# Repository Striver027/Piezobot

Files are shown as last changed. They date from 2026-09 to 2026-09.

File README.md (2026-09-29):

# Piezobot

**A desktop-scale, low-cost stick–slip piezoelectric robot for validating
swarm-intelligence algorithms that require fine relative positioning.**

This repository contains the editable hardware design files and firmware that
accompany the HardwareX article on Piezobot. It is intended to be sufficient for
another group to reproduce the robot and reproduce the measurements reported in
the article.

---

## Overview

Piezobot is a small mobile robot whose motion is produced by a **stick–slip
(friction–inertia) mechanism**: two piezoelectric stacks drive the robot across a
flat ferromagnetic surface, while N52 permanent magnets simultaneously provide the
preload force and the friction surface. Driving the stacks with a sawtooth waveform
generates a small net displacement on every cycle, which accumulates into
centimetre-scale travel. Turning is obtained by switching off the drive signal of one
of the two channels.

The robot is built from **stacked PCBs**, so the mechanical structure requires almost
no fasteners and the boards can be substituted to suit different experiments. Its
small size (3.7 cm body diameter) allows a high density of individuals to be placed
within a single camera field of view, which is what makes it useful as a
swarm-robotics test platform.

## Key specifications

| Parameter | Value |
|---|---|
| Body diameter | 3.7 cm |
| Actuation | 2 × piezoelectric stacks, stick–slip (friction–inertia) |
| Preload / friction surface | N52 permanent magnets |
| Drive voltage | 30 V (single Li-ion cell + on-board boost converter) |
| Drive waveform | Sawtooth, 2 kHz, generated by timer-triggered DMA (open loop) |
| Measured travelling speed | ≈ 1.6 mm/s (16 mm in 10 s) |
| Net displacement per drive cycle | ≈ 0.8 µm |
| Steering | Differential — switching off one drive channel turns the robot |
| Position holding | Retained when the drive signal is removed |
| Communication | 433 MHz wireless module |
| Working surface | Flat, ferromagnetic (tests performed on 430 stainless steel) |

> Piezobot is an **open-loop, single-prototype** platform at this stage: displacement
> is estimated from the number of drive cycles, with no position feedback. Positioning
> error is intended to be compensated by the vision system of the swarm-validation
> platform.

## Repository structure

```
Piezobot/
├── README.md                 This file
├── LICENSE                   CC BY-SA 4.0 (full legal text)
├── Hardware/                 Editable PCB source projects, PDFs and Gerber files
│   └── README.md             File-by-file inventory of the hardware folder
├── CAD/                      Mechanical CAD: Fusion 360 sources and neutral STEP files
│   └── README.md             Description of the CAD files
├── Docs/                     Documentation and the editable bill of materials
│   ├── README.md             Index of the documentation
│   └── BOM_<board>.xlsx      Editable bill of materials, one file per board
└── firmware/                 STM32 firmware — to be added before the v1.0 release
```

## Hardware

Four boards are stacked, from bottom to top: **PZT → power → controller → function**. They
share a common power and signal interface. Above the stack, at the very top of the robot,
sits the **LCD board**: the 0.99-inch display is taped onto it, the display ribbon cable is
soldered to it, and it converts the display signals into an FPC interface that connects to
the controller board. Neither the DAP board nor the BAT board is part of the stack: the DAPLink-end adapter in the
DAP board panel is used only as an aid for flashing the firmware, and the BAT board is the
battery adapter that powers the robot.

| Board | Function |
|---|---|
| **PZT board** (bottom of the stack) | Carries and wires the piezoelectric stacks |
| **Power board** | Boost converter (3.7 V → 30 V) and power operational amplifier that generates the drive waveform |
| **Controller board** | STM32G431 main controller; two DAC channels generate the sawtooth waveforms; the FPC from the LCD board connects here |
| **Function board** (top of the stack) | Six-axis IMU and 433 MHz wireless module |
| **LCD board** (above the stack, topmost part of the robot) | Display base board: the 0.99-inch display is taped onto it and its ribbon cable is soldered to it; converts the display signals into an FPC interface |
| **DAP board** (outside the stack) | Panelized adapter (PowerLink 2.54 mm ↔ 0.8 mm BTB): one larger link-end adapter board plus two smaller boards (programming, two batteries); the link-end adapter is used to flash the firmware |
| **BAT board** (outside the stack) | Battery adapter with the same panel structure and layout as the DAP board, but with thickened lead connections, so the two are not interchangeable; used to retrofit the battery that powers the robot |

The PCB sources are **Altium Designer** files (`.PrjPcb`, `.SchDoc`, `.PcbDoc`);
PDF schematics and fabrication-ready Gerber/drill archives are provided alongside them
so that the boards can be reviewed and manufactured without Altium. See
[`Hardware/README.md`](Hardware/README.md) for the complete file inventory.

The mechanical design is provided in [`CAD/`](CAD) in two formats: the editable
Autodesk Fusion 360 sources (`Piezobot_Assembly.f3z`, `CNC/aluminium_base.f3d`) and the
same geometry as neutral STEP files (`Piezobot_Assembly.step`, `CNC/aluminium_base.step`).
The assembly contains all parts of the robot, including the CNC-machined aluminium base
and the 3D-printed shell and LCD retaining ring; the parts to be printed are also
provided as STL. See [`CAD/README.md`](CAD/README.md) for the file inventory.

## Firmware

The firmware runs on an STM32G4-series microcontroller. It generates two 12-bit
sawtooth waveforms through the internal DACs, which the power board amplifies to 30 V
to drive the piezoelectric stacks. The waveform is produced by a timer triggering DMA
transfers, and the travelling speed is controlled by changing the driving frequency
(within the tested range, speed is approximately proportional to frequency).

**Firmware source code: `firmware/` — _to be added before the v1.0 release._**

## Getting started

1. Assemble the robot following the article (see *How to cite* below). Details of the
   assembly, including the magnet orientation, the glue points and the contact
   resistance check between the brass screw and the base, are given in the article's
   build instructions.
2. Charge/connect the single Li-ion cell.
3. Place the robot on a flat ferromagnetic surface (the article reports measurements on
   a 430 stainless steel plate).
4. Power the robot: the controller starts generating the 2 kHz sawtooth waveform and
   the robot begins stepping.
5. To change speed, change the driving frequency. To turn, disable the drive signal on
   one of the two channels.
6. Remove the drive signal to stop; the magnets hold the robot in place.

⚠️ **Safety:** the board generates up to 30 V and the magnets are strong N52 magnets —
take care with the boost converter output and avoid pinching fingers between the
magnets and the steel plate. Instant adhesive is used during assembly.

## Bill of materials

Components other than the PCBs. The electronics are itemised board by board in the
editable files in [`Docs/`](Docs) (`BOM_<board>.xlsx`, one per board, in the same column
format as the article's Bill of materials summary).

| Component | Type | Specification | Qty |
|---|---|---|---|
| NdFeB magnet (N52) | Drive | — | 4 |
| piezoelectric stack | Drive | AL1.65×1.65×5D-4F | 2 |
| shell | Structure | 3D printed | 1 |
| LCD retaining ring | Structure | 3D printed | 1 |
| aluminium base | Structure | CNC machined (aluminium) | 1 |
| brass cap screw | Structure | M2.5 × 4 | 2 |
| brass ball plunger | Friction | M4 | 3 |
| FPC | Wiring | — | 1 |
| instant adhesive (401) | Consumable | — | — |
| magnetic pole indicator card | Tool | — | — |

## Documentation

Additional documentation is collected in the [`Docs/`](Docs) folder:

- [`Docs/README.md`](Docs/README.md) — index of the assembly figures, wiring diagram and
  operating notes;
- [`Docs/`](Docs) — editable bills of materials, one file per board (`BOM_<board>.xlsx`),
  in the column format used by the article.

## Licence

All design files in this repository are released under the
**[Creative Commons Attribution-ShareAlike 4.0 International (CC BY-SA 4.0)](LICENSE)**
licence: you are free to use, modify and redistribute them, provided that you give
appropriate credit and license any derivative work under the same terms.

## How to cite

If you use Piezobot in your work, please cite **both** the article and this repository.

**Article**

> *(citation to be completed once the HardwareX article is published)*

**This repository**

```bibtex
@software{piezobot_v1,
  author  = {Xing, Zhizhou},
  title   = {Piezobot: design files and firmware for a stick--slip piezoelectric
             robot for swarm-intelligence algorithm validation},
  year    = {2026},
  version = {v1.0},
  doi     = {10.5281/zenodo.XXXXXXX},
  url     = {https://github.com/Striver027/Piezobot}
}
```

*(The Zenodo DOI will be inserted here once the v1.0 release has been archived.)*

## Contact

Xing Zhizhou — Hebei University of Science and Technology, Shijiazhuang, China
Corresponding author, HardwareX article: `2024102026@stu.hebust.edu.cn`

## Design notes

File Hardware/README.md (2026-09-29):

# Hardware — Piezobot hardware design files

Editable PCB design files for the Piezobot robot

All files in this folder are released under the
**Creative Commons Attribution-ShareAlike 4.0 International (CC BY-SA 4.0)** licence.
See the repository root [`LICENSE`](../LICENSE) for the full text.

---

## File inventory

### Stack order (bottom → top)

| # | Board |
|---|---|
| 1 (bottom) | PZT board |
| 2 | Power board |
| 3 | Controller board |
| 4 (top) | Function board |

The **LCD board** sits above the stack and is the topmost part of the whole robot; its FPC
connects to the controller board.
The **DAP board** and the **BAT board** are not part of the stack and are used only for some
auxiliary functions. In the panels of the DAP board and the BAT board, the larger part is the
DAPLink-end adapter. The small board in the DAP board is an adapter for connecting to the
robot end, and the small board in the BAT board is the battery adapter that powers the robot.

### Project files (open these first)

| File | Format | Purpose |
|---|---|---|
| `Piezobot.PrjPcb` | Altium project | **Master project** — open it with Altium Designer to browse all the schematics and PCB layouts below |
| `Piezobot.OutJob` | Altium output job | Fabrication and documentation output settings for the project |

### PZT board (piezoelectric stack carrier and wiring)

Stack position: bottom (1st from the bottom).

| File | Format | Purpose |
|---|---|---|
| `PZT_board.SchDoc` | Altium schematic | Schematic |
| `PZT_board.PcbDoc` | Altium PCB | PCB layout |
| `PZT_board.pdf` | PDF | Schematic (for viewing without Altium) |
| `PZT_board.zip` | Gerber + drill | Ready for PCB fabrication |

### Power board (boost converter + power operational amplifier)

Stack position: 2nd from the bottom.

| File | Format | Purpose |
|---|---|---|
| `power_board.SchDoc` | Altium schematic | Schematic |
| `power_board.PcbDoc` | Altium PCB | PCB layout |
| `power_board.pdf` | PDF | Schematic (for viewing without Altium) |
| `power_board.zip` | Gerber + drill | Ready for PCB fabrication |

### Controller board (STM32G431 main controller)

Stack position: 3rd from the bottom; the FPC of the LCD board connects to this board.

| File | Format | Purpose |
|---|---|---|
| `controller_board.SchDoc` | Altium schematic | Schematic |
| `controller_board.PcbDoc` | Altium PCB | PCB layout |
| `controller_board.pdf` | PDF | Schematic (for viewing without Altium) |
| `controller_board.zip` | Gerber + drill | Ready for PCB fabrication |

### Function board (IMU + 433 MHz wireless module)

Stack position: top (4th from the bottom).

| File | Format | Purpose |
|---|---|---|
| `function_board.SchDoc` | Altium schematic | Schematic |
| `function_board.PcbDoc` | Altium PCB | PCB layout |
| `function_board.pdf` | PDF | Schematic (for viewing without Altium) |
| `function_board.zip` | Gerber + drill | Ready for PCB fabrication |

### LCD board (screen base board, topmost part of the whole robot)

The 0.99-inch LCD screen is taped onto this board, and the screen ribbon cable is soldered to
this board. This board serves as the base board of the screen and adapts the screen signal
cable to an FPC, which is connected to the controller board through the FPC. It sits above the
stack and is the topmost part of the whole robot.

| File | Format | Purpose |
|---|---|---|
| `LCD_board.SchDoc` | Altium schematic | Schematic |
| `LCD_board.PcbDoc` | Altium PCB | PCB layout |
| `LCD_board.pdf` | PDF | Schematic (for viewing without Altium) |
| `LCD_board.zip` | Gerber + drill | Ready for PCB fabrication |

### DAP board (DAPLink adapter, panelized)

A simple adapter board: different types of connectors are adapted through this circuit board.
The layout of this board is **panelized**: it can adapt the 2.54 mm interface of PowerLink to a
0.8 mm BTB interface. The large board is used to first convert 2.54 mm into 1.27 mm pin
headers, and the small board is used to convert the 1.27 mm pin headers into a 0.8 mm BTB
interface.

| File | Format | Purpose |
|---|---|---|
| `DAP_board.SchDoc` | Altium schematic | Schematic |
| `DAP_board.PcbDoc` | Altium PCB | Panelized layout |
| `DAP_board.pdf` | PDF | Schematic (for viewing without Altium) |
| `DAP_board.zip` | Gerber + drill | Gerber and drill files of the panelized version |

### BAT board (battery adapter, panelized)

Battery adapter board. It has exactly the same structure and layout as the DAP board, but the
lead connections inside the board have been thickened and copper-poured, so the **DAP board and
the BAT board are not interchangeable**: only their large boards are the same — the large board
in the BAT panel can still be connected to a DAPLink programmer, while the small board is used
to retrofit a lithium-battery connector to power the robot.

| File | Format | Purpose |
|---|---|---|
| `BAT_board.SchDoc` | Altium schematic | Schematic |
| `BAT_board.PcbDoc` | Altium PCB | Panelized layout |
| `BAT_board.pdf` | PDF | Schematic (for viewing without Altium) |
| `BAT_board.zip` | Gerber + drill | Gerber and drill files of the panelized version |

---

## PCB fabrication parameters

| Board | Layers | Board thickness |
|---|---|---|
| PZT board | 2 | 1.0 mm |
| Power board | 2 | 1.6 mm |
| Controller board | 4 | 1.6 mm |
| Function board | 2 | 1.2 mm |
| LCD board | 2 | 1.2 mm |
| DAP board | 2 | 1.6 mm |
| BAT board | 2 | 1.6 mm |

Except for the controller board, which is a four-layer board (laminate order from top to
bottom: top layer / mid-layer 1 / mid-layer 2 / bottom layer), all the other boards are
two-layer boards.

The copper weight follows the manufacturer's (JLCPCB) default process: **1 oz on the outer
layers and 0.5 oz on the inner layers** (the inner-layer value applies to the four-layer
controller board).

---

## How to open these files

- **To edit the electronics**: use **Altium Designer** (the `.PrjPcb` project opens all the
  schematics and layouts together). You can also view them in a browser with the free
  **Altium 365 Viewer**.
- **To view without Altium**: use the `.pdf` file of each board (schematic).
- **To fabricate**: send the contents of the corresponding `.zip` (Gerber + drill) to any PCB
  manufacturer.

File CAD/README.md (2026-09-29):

# CAD — Piezobot mechanical design files

Mechanical CAD and 3D-printing files for the Piezobot robot.

All files in this folder are released under the
**Creative Commons Attribution-ShareAlike 4.0 International (CC BY-SA 4.0)** licence.
See the repository root [`LICENSE`](../LICENSE) for the full text.

---

## File inventory

```
CAD/
├── Piezobot_Assembly.f3z               Complete robot assembly (Fusion 360 archive)
├── Piezobot_Assembly.step              Complete robot assembly (neutral STEP)
├── CNC/
│   ├── aluminium_base.f3d              CNC-machined aluminium base (Fusion 360 part)
│   └── aluminium_base.step             CNC-machined aluminium base (neutral STEP)
└── STLs(3D Print)/
    ├── shell.stl                       3D-printed shell
    └── LCD_retaining_ring_0.99in.stl   3D-printed retaining ring for the 0.99-inch LCD
```

| File | Format | Description |
|---|---|---|
| `Piezobot_Assembly.f3z` | Fusion 360 archive | Complete robot assembly — every part is in its assembled position; open this file first if you use Autodesk Fusion 360 |
| `Piezobot_Assembly.step` | STEP assembly | The same complete assembly in neutral STEP format, for any other CAD software |
| `CNC/aluminium_base.f3d` | Fusion 360 part | CNC-machined aluminium base |
| `CNC/aluminium_base.step` | STEP part | The same part in neutral STEP format |
| `STLs(3D Print)/shell.stl` | STL part | 3D-printed shell |
| `STLs(3D Print)/LCD_retaining_ring_0.99in.stl` | STL part | Retaining ring for the 0.99-inch LCD |

## How to use these files

- `Piezobot_Assembly.f3z` and `CNC/aluminium_base.f3d` open directly in Autodesk Fusion 360; the `.step` files carry the same geometry in a neutral format that any CAD software can import.
- `Piezobot_Assembly` contains the whole robot; you can locate a part in the assembly to see its assembled state and position.
- The two `.stl` files can be sliced and 3D printed directly.
- The assembly steps of the mechanical parts are described step by step in the accompanying HardwareX article: including the base and the stick–slip mechanism, the fixing and wiring of the PZT board, and the assembly of the screen, retaining ring and shell.

## Fabrication

| File | Process |
|---|---|
| `CNC/aluminium_base.step` | CNC machining (6061 aluminium) |
| `STLs(3D Print)/shell.stl` | 3D printing (PLA material, 0.2 mm nozzle) |
| `STLs(3D Print)/LCD_retaining_ring_0.99in.stl` | 3D printing (same process as above) |

More detailed printing and machining parameters (material, layer height, infill, etc.) are given in the accompanying article.

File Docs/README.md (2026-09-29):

# Documentation — Piezobot

Supporting documentation for building, operating and reproducing the Piezobot robot.

Everything in this folder is released under the
**Creative Commons Attribution-ShareAlike 4.0 International (CC BY-SA 4.0)** licence.
See the repository root [`LICENSE`](../LICENSE) for the full text.

---

## Bill of materials

The electronics are itemised board by board — one editable spreadsheet per board:

| File | Board |
|---|---|
| `BOM_PZT_board.xlsx` | PZT board |
| `BOM_power_board.xlsx` | power board |
| `BOM_controller_board.xlsx` | controller board |
| `BOM_function_board.xlsx` | function board |
| `BOM_LCD_board.xlsx` | LCD board |
| `BOM_DAP_board.xlsx` | DAP board |
| `BOM_BAT_board.xlsx` | BAT board |

Every file uses exactly the same columns as the *Bill of materials summary* in the
article:

```
Designator, Component, Number of units, Cost per unit - CNY,
Total cost - CNY, Source of materials, Material type
```

The first row of each file is the bare-board fabrication cost (JLCPCB, 21.6 CNY per
board). The `Source of materials` cells are hyperlinks to *Taobao* or *LCSC*. The total
of each file is the cost of that board.

The parts other than the PCBs, together with the board-level totals, are listed in the
*Bill of materials summary* of the article.

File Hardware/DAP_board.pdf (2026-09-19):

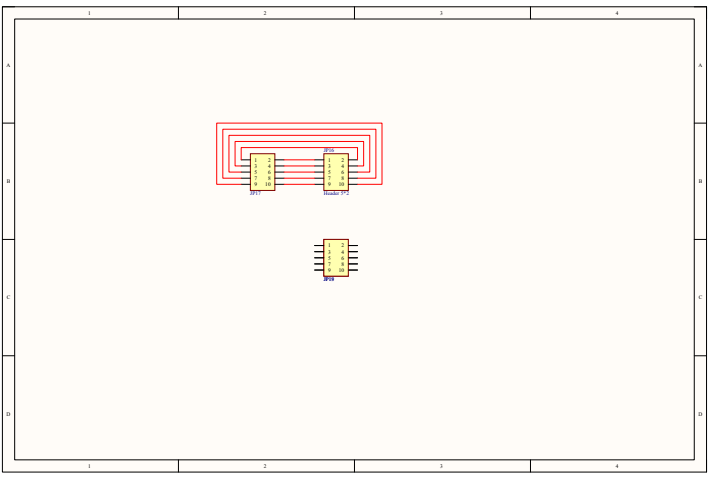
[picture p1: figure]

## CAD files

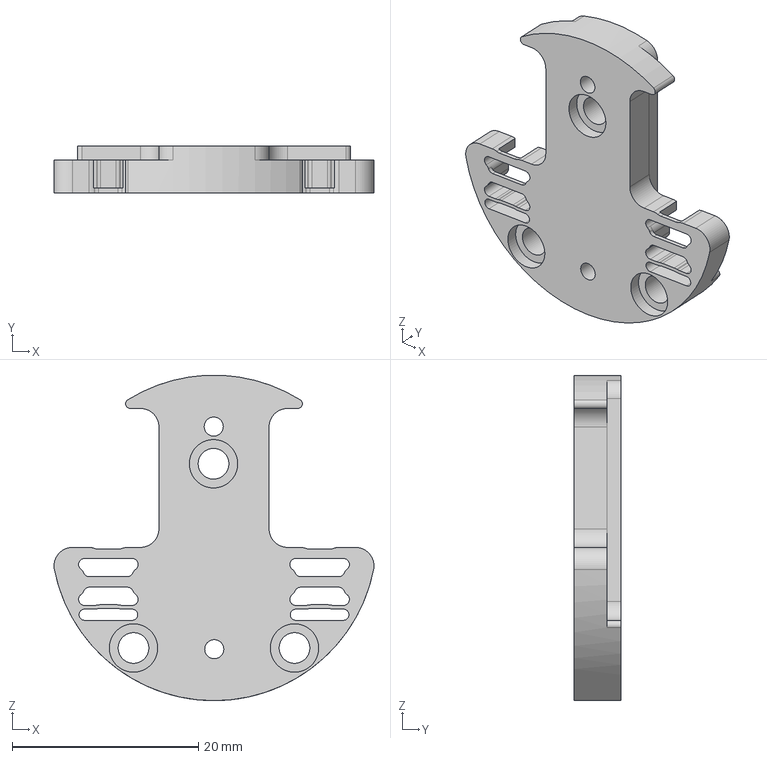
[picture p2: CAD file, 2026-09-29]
CAD/CNC/aluminium_base.step
34.4 x 5.00 x 35.0 mm

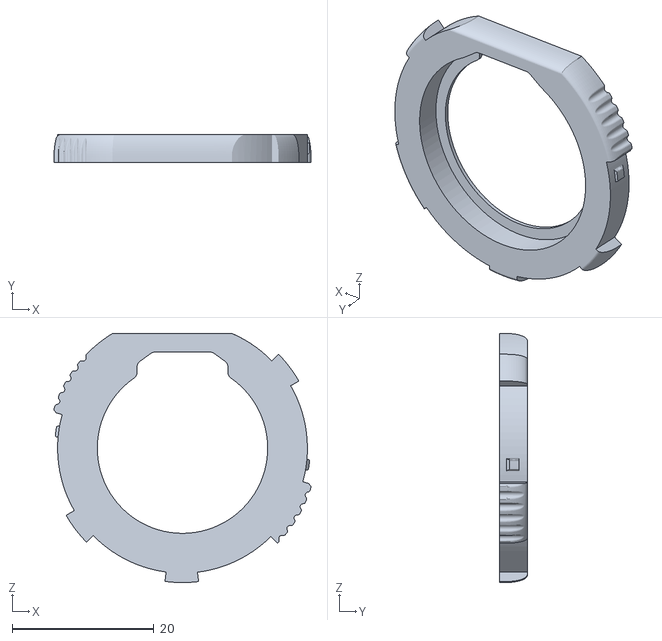
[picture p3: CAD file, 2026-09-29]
CAD/STLs(3D Print)/LCD_retaining_ring_0.99in.stl
36.2 x 3.90 x 35.1

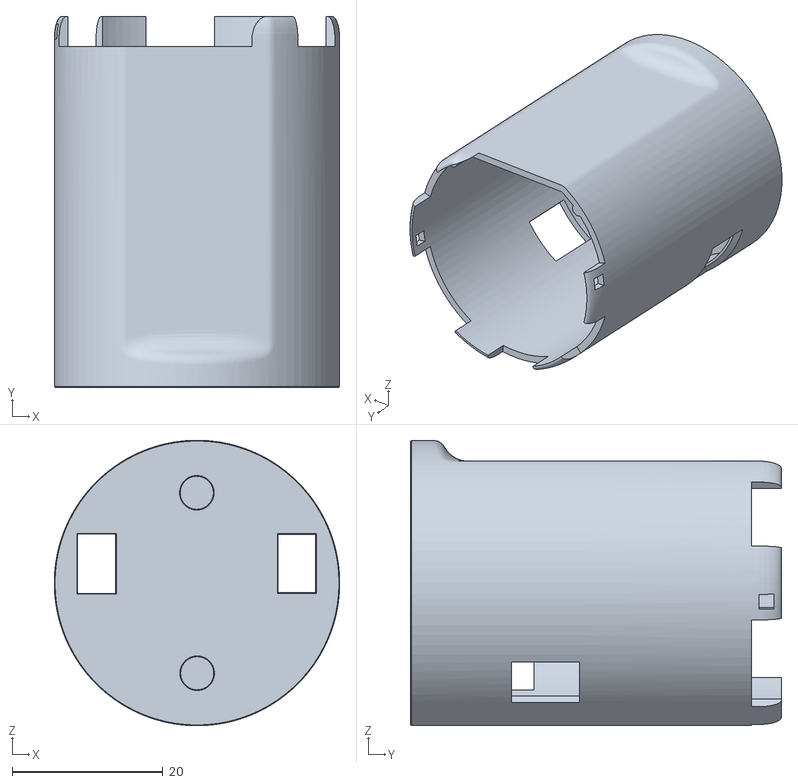
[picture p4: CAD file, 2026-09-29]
CAD/STLs(3D Print)/shell.stl
37.9 x 49.2 x 37.9

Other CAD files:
CAD/CNC/aluminium_base.f3d

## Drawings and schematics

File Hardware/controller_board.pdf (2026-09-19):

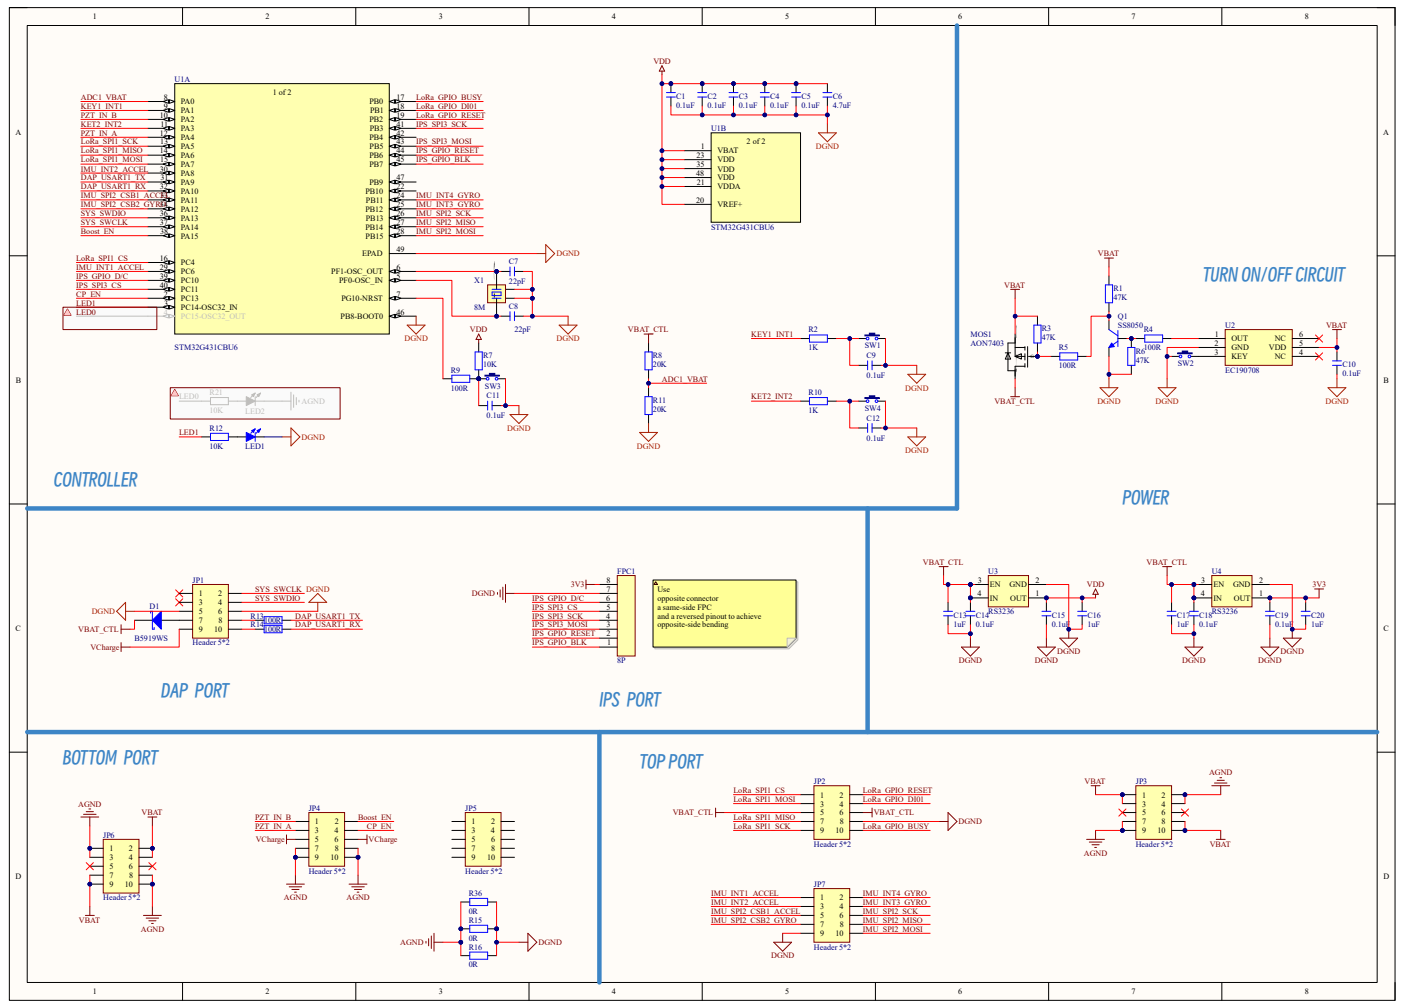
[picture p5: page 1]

TURN ON/OFF CIRCUIT

Use
opposite connector
a same-side FPC
and a reversed pinout to achieve
opposite-side bending

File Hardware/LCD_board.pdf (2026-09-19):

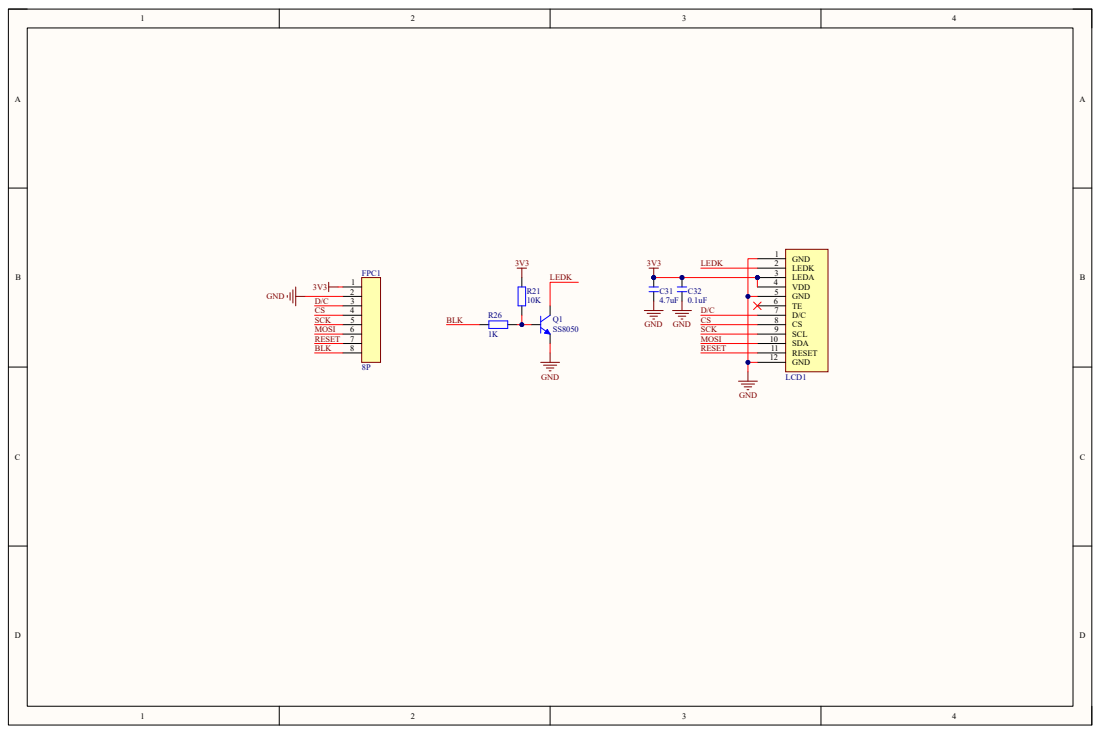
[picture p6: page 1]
GND; LEDK; LEDA; VDD; SCL; SDA; RESET; LCD1; D/C CS SCK MOSI RESET; GND GND; BLK; FPC1; MOSI; SCK

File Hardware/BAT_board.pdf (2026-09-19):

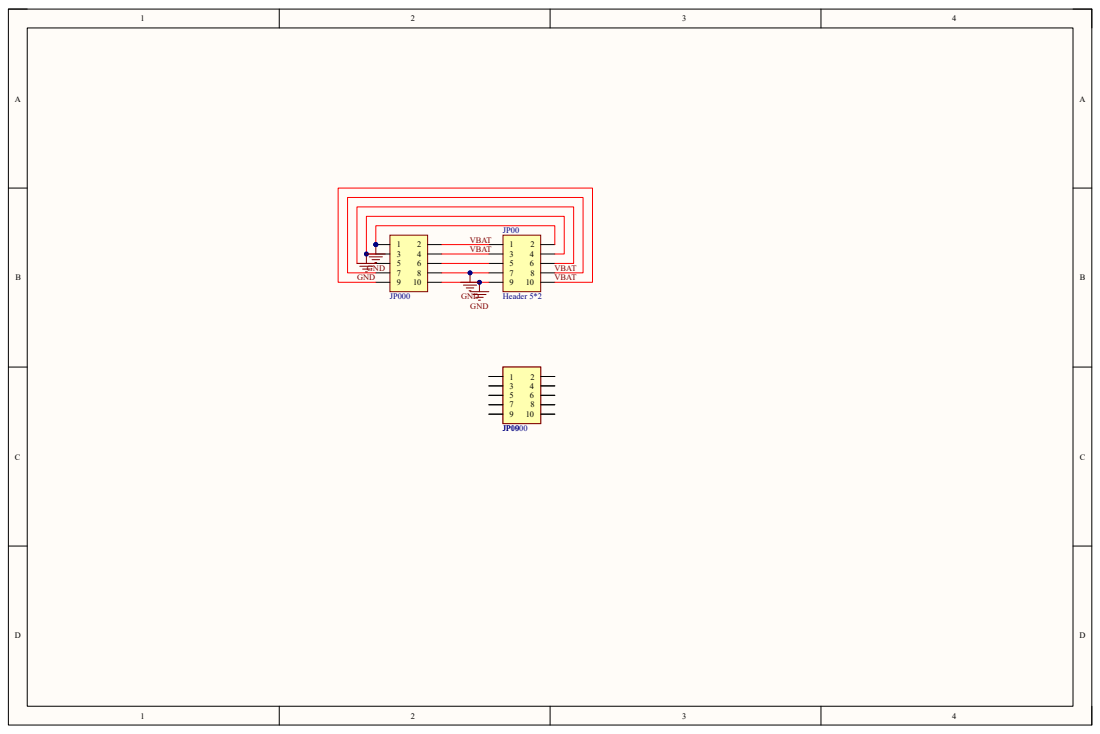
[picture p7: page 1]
DGN

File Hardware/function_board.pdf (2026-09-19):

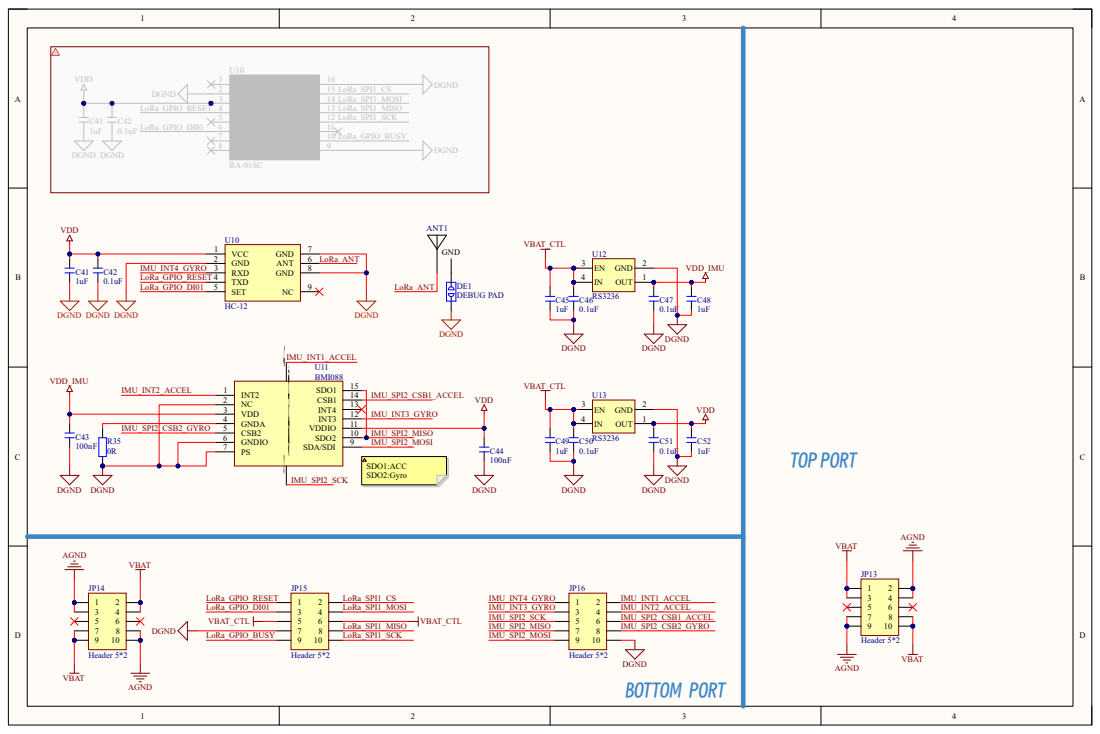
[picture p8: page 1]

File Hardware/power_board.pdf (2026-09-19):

# TOP PORT

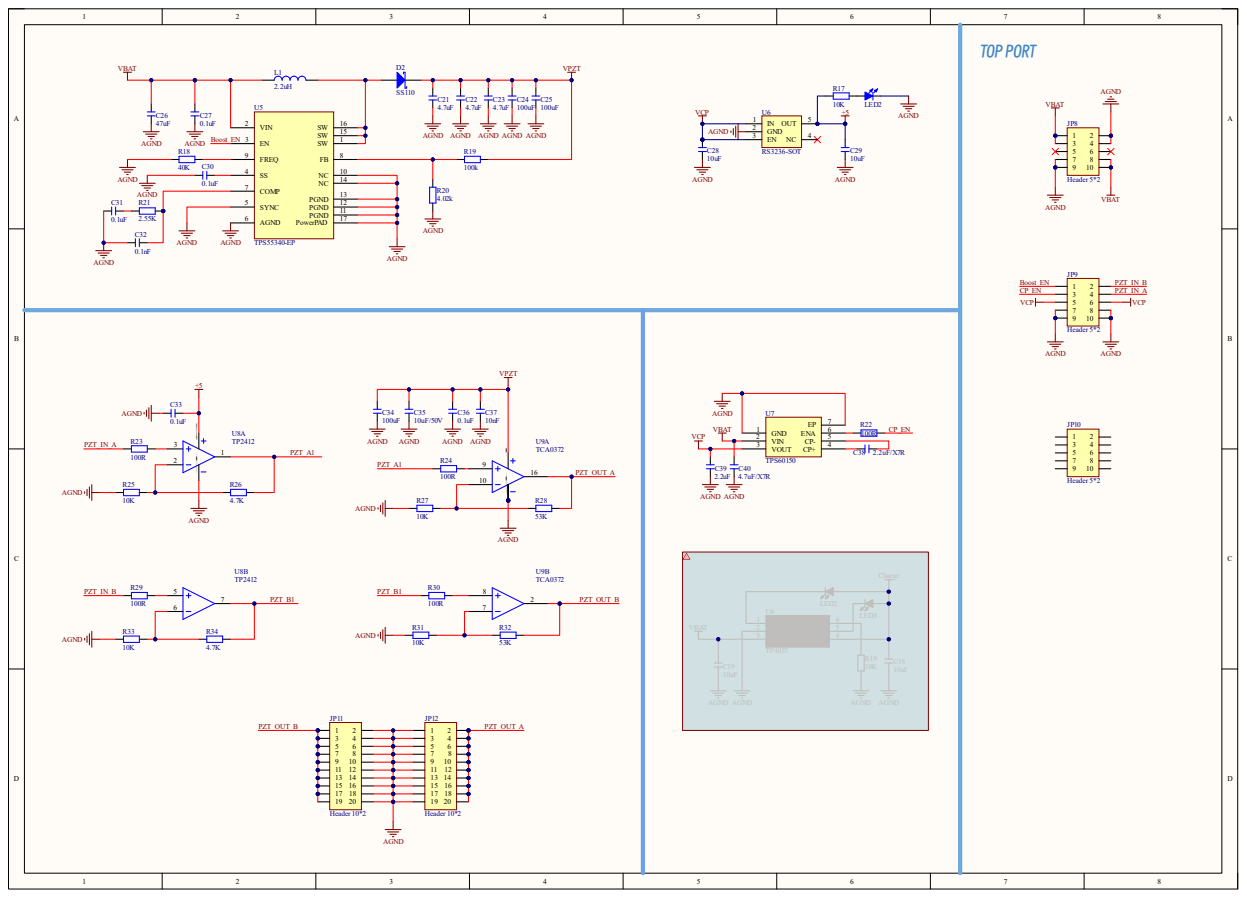
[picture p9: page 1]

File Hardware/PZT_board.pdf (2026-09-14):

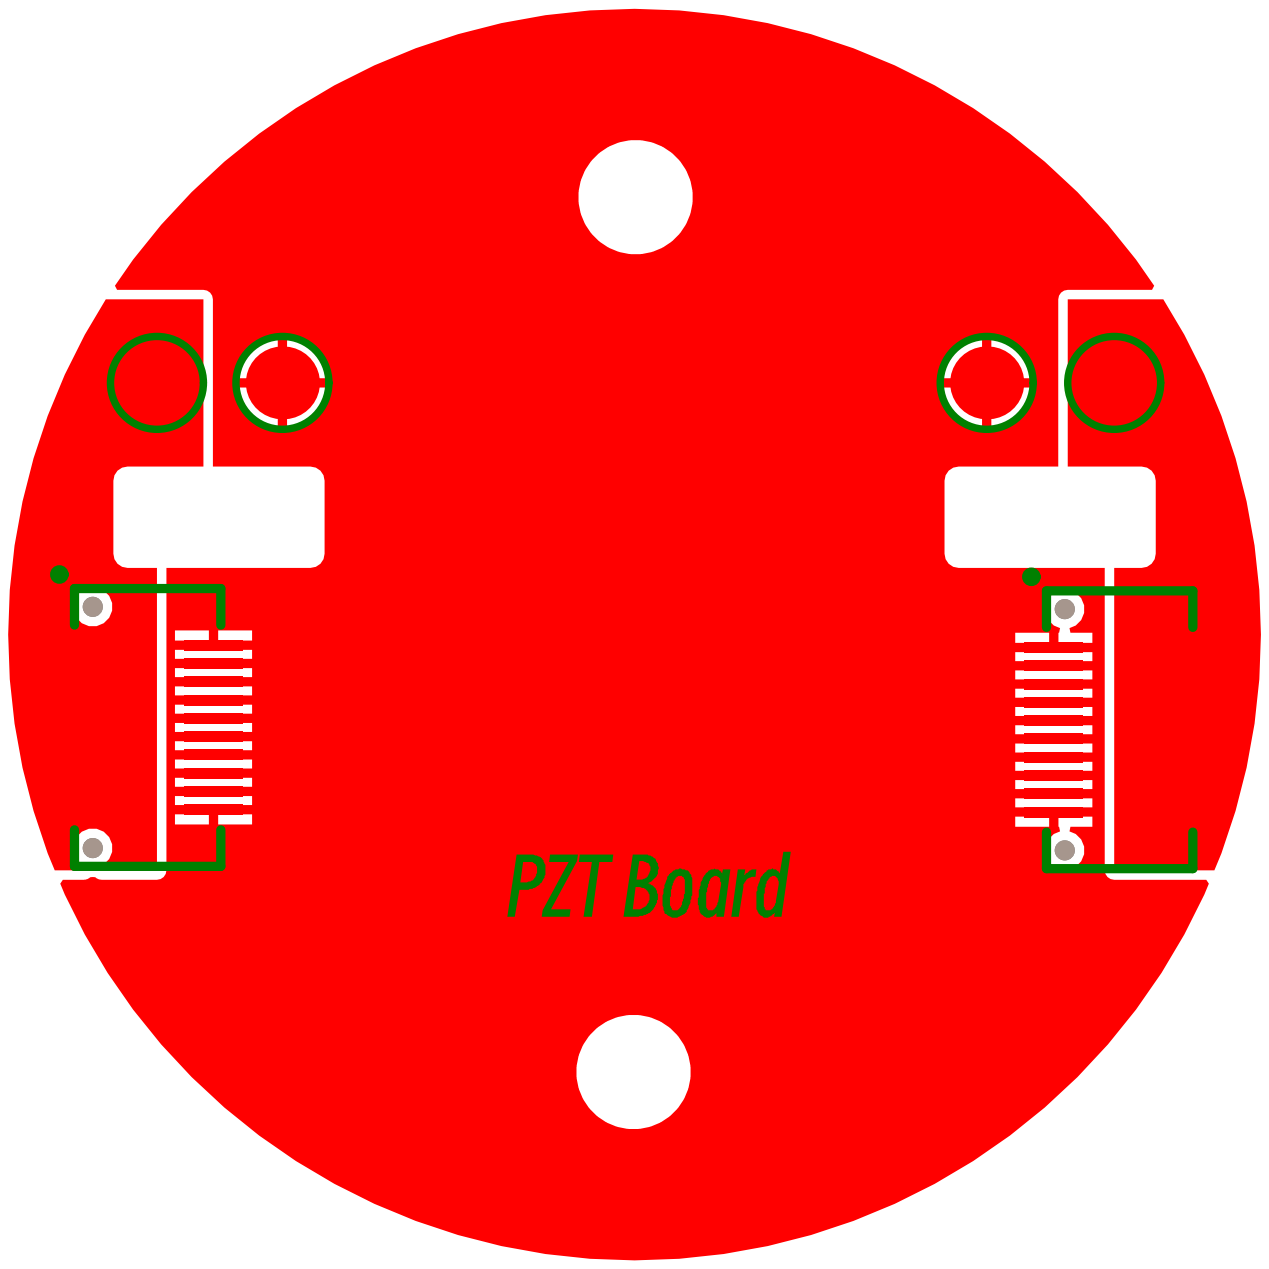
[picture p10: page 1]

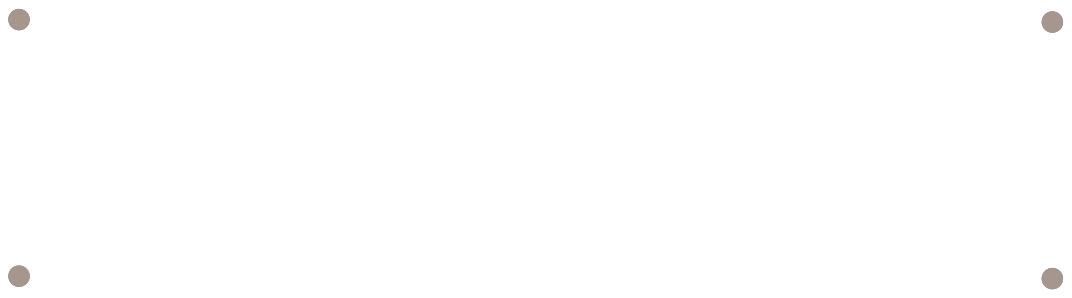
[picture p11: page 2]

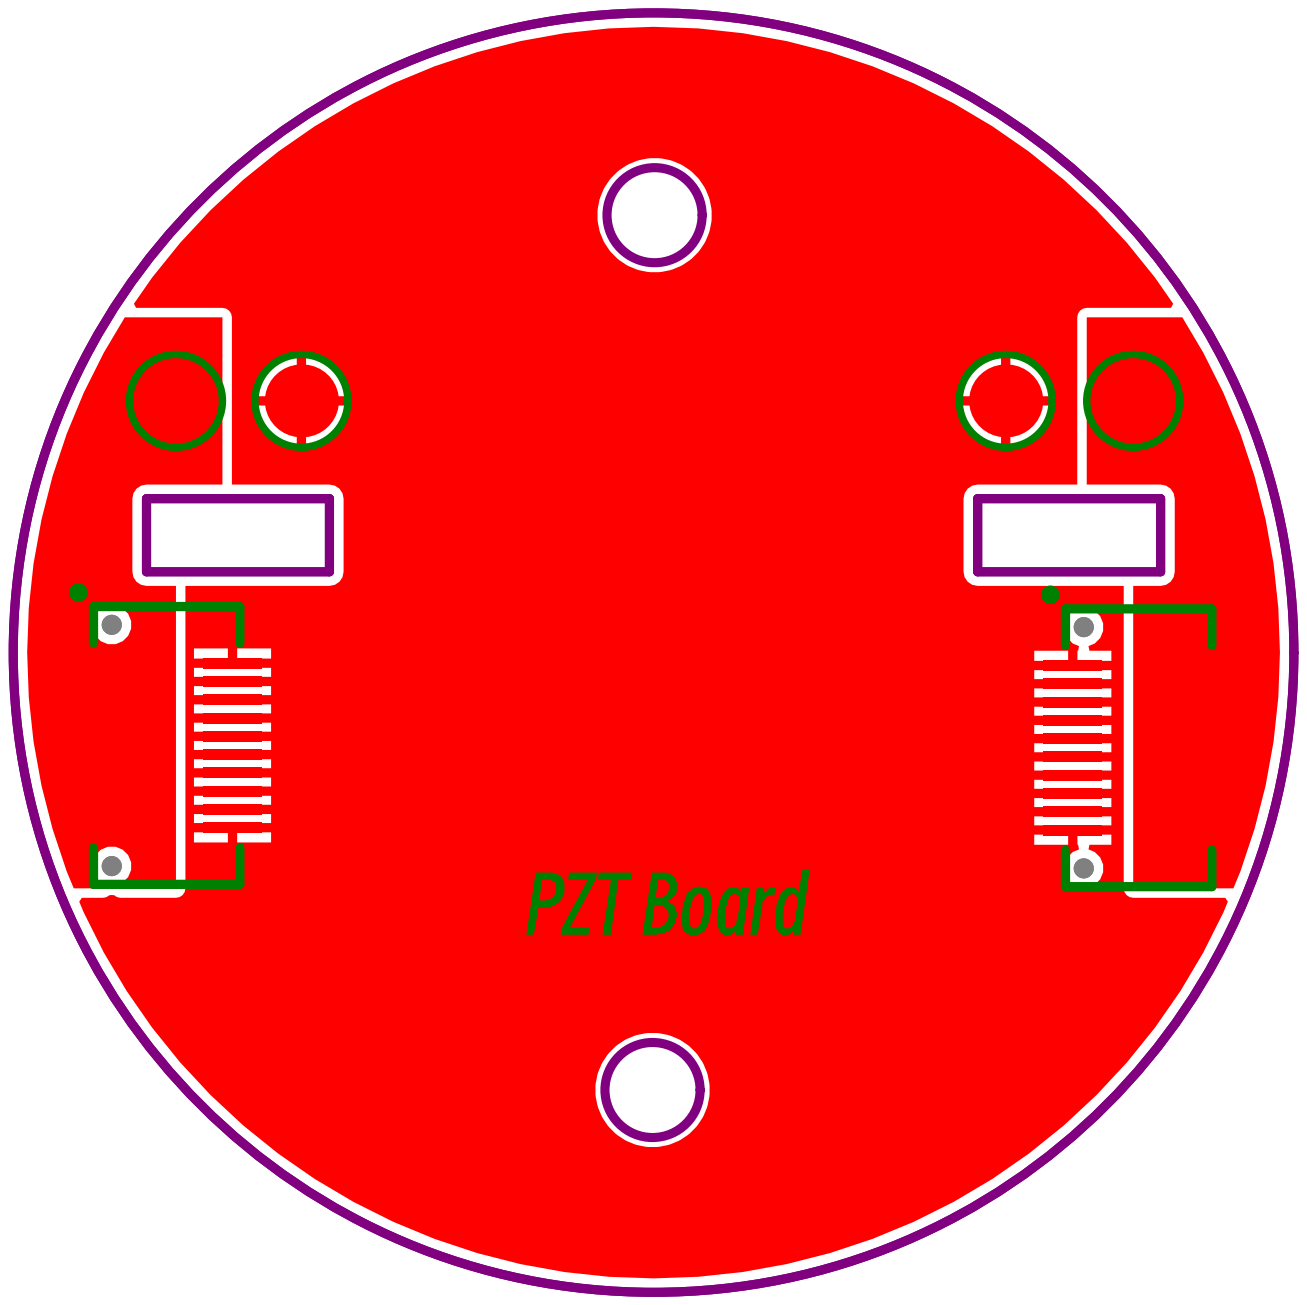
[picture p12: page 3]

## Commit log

2026-09-14 Add files via upload
    Hardware
    [Controller Board V0.3.PcbDoc, Controller Board V0.3.SchDoc, DAP Board V0.3 single.PcbDoc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]
2026-09-14 Move some files
    [Controller Board V0.3.PcbDoc, Controller Board V0.3.SchDoc, DAP Board V0.3 single.PcbDoc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]
2026-09-19 add some files
    [BAT Board.PcbDoc, BAT Board.SchDoc, BOM.csv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]
